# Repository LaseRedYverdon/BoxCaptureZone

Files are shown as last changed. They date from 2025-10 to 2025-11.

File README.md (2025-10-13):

# Box Capture de Zone – LaseRed Yverdon

##  Cahier des charges

- **But du projet** : Coffre électronique avec digicode, boutons lumineux, LEDs RJB, son, et verrouillage par électro-aimant.

- **Contraintes** :
    
    - Matériel robuste (usage intensif).
        
    - Maintenance simple.
        
    - Audio de bonne qualité.
        
    - Mise à jour facile des énigmes et sons gérées à distance. 
        
    - Intégration dans un coffre résistant.

---

****
##  Architecture générale

### Schéma fonctionnel

```mermaid
graph TD
    A[Clavier numérique] -->|Entrée code| B[Arduino UNO]
    B -->|Contrôle| C[Électro-aimant]
    B -->|Affiche énigme| D[Écran digital]
    B -->|État LEDs| E[10 LEDs RJB]
    B -->|Boutons équipe| F[4 Boutons lumineux]
    G[Raspberry Pi] -->|Énigme / Code| B
    G -->|Audio / Musique| H[Haut-parleur + ampli]
```

```

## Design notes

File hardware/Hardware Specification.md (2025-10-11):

# Hardware Specification

**Date :** 11/10/2025  
**Version :** 1.0

---

## Vue d’ensemble

- L’Arduino Nano est **alimenté directement par le Raspberry Pi** via le câble USB (5V).
    
- Le Raspberry Pi et l’Arduino partagent la **masse commune (GND)**.
    
- La **communication** entre Nano et Raspberry se fait par **USB série**. Avec le cable d'alimentation du nano
    
- Le **12 V** est utilisé uniquement pour : électro-aimant, relais et luminaires (géré par le raspberry).
    
- Tous les périphériques externes (digikey, boutons, LCD, électro-aimant, relais) doivent être branchés via des **connecteurs amovibles** (borniers ou connecteurs à levier).

---

## Schéma simplifié

```
                 +---------------------+
                 |     ARDUINO NANO    |
                 |                     |
        5V  <----| Alimentation depuis Raspberry Pi |
       GND  <----| Masse commune avec Raspberry Pi et périphériques |
                 |                                |
        D0  ---->| Libre / réservé debug          |
        D1  ---->| Libre / réservé debug          |
        D2  ---->| DATA0 Wiegand <-----+---- Clavier métallique Wiegand 26
        D3  ---->| DATA1 Wiegand <-----+---- Clavier métallique Wiegand 26
        D4  ---->| Bouton ROUGE  <-----+---- Bouton poussoir LED 16mm
        D5  ---->| Bouton BLEU   <-----+---- Bouton poussoir LED 16mm
        D6  ---->| Bouton JAUNE  <-----+---- Bouton poussoir LED 16mm
        D7  ---->| Bouton VERT   <-----+---- Bouton poussoir LED 16mm
        D8  ---->| Relais ROUGE  ----> Commande relais (électro-aimant)
        D9  ---->| Relais BLEU   ----> Commande relais (lampes ou autre charge)
       D10  ---->| 74HC595 LATCH ----> Latch pin 74HC595 (pour LEDs RJB)
       D11  ---->| 74HC595 DATA ----> Data pin 74HC595 (pour LEDs RJB)
       D12  ---->| Libre / futur usage audio (géré par Raspberry)
       D13  ---->| 74HC595 CLOCK ---> Clock pin 74HC595 (pour LEDs RJB)
        A4  <--> | I2C SDA  <--------> LCD 1602 I2C (connecteur externe)
        A5  <--> | I2C SCL  <--------> LCD 1602 I2C (connecteur externe)
       A0-A3     | Libre (capteurs/futurs)
       A6-A7     | Libre (capteurs/futurs)
                 +---------------------+

   Entrée 12V : embout rond DC → Relais / électro-aimant / lampes
   Connecteurs externes :
     • Clavier Wiegand (4 fils)
     • Boutons LED (3 fils chacun : signal, +5V, GND)
     • LCD I2C (4 fils)
     • Relais pour électro-aimant et lampes
     • Alimentation 12V
```

---

## Branchements détaillés

**Clavier Wiegand 26**

```
   +12V  ---> VCC clavier
   GND   ---> GND commun
   DATA0 ---> D2 Nano
   DATA1 ---> D3 Nano
   Connecteur 4 broches
```

**Boutons poussoirs LED**

```
   D4/D5/D6/D7 ---> entrée signal
   Autre côté bouton ---> GND
   LED intégrée (si présente) ---> +5V via résistance
   Connecteur 3 broches : Signal / +5V / GND
```

**Shift register 74HC595 (10 LEDs RJB)**

```
   D10 ---> LATCH
   D11 ---> DATA
   D13 ---> CLOCK
   QA–QH ---> LEDs (via résistances) ---> GND
   Si plus de 8 LEDs : cascade second 74HC595
```

**Relais (électro-aimant et lampes)**

```
   D8/D9 ---> IN1/IN2 du module relais
   VCC module ---> 5V Nano
   GND module ---> GND commun
   Sortie relais :
     COM ---> entrée 12V (embout DC)
     NO  ---> électro-aimant ou lampe
   Protection : diode roue libre si DC
```

**LCD 1602 I²C**

```
   SDA ---> A4
   SCL ---> A5
   VCC ---> 5V
   GND ---> GND
   Connecteur 4 broches
```

**Communication avec Raspberry Pi**

```
   USB Nano <--> Raspberry Pi
   Alimentation + communication série
   GND commun
```

**Alimentation générale**

```
   5V Nano <--- Raspberry Pi
   12V ---> relais / électro-aimant / lampes
   GND commun
```

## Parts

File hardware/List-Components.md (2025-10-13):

## List of components

### 🔹 1. Unité de contrôle

- **Arduino UNO**

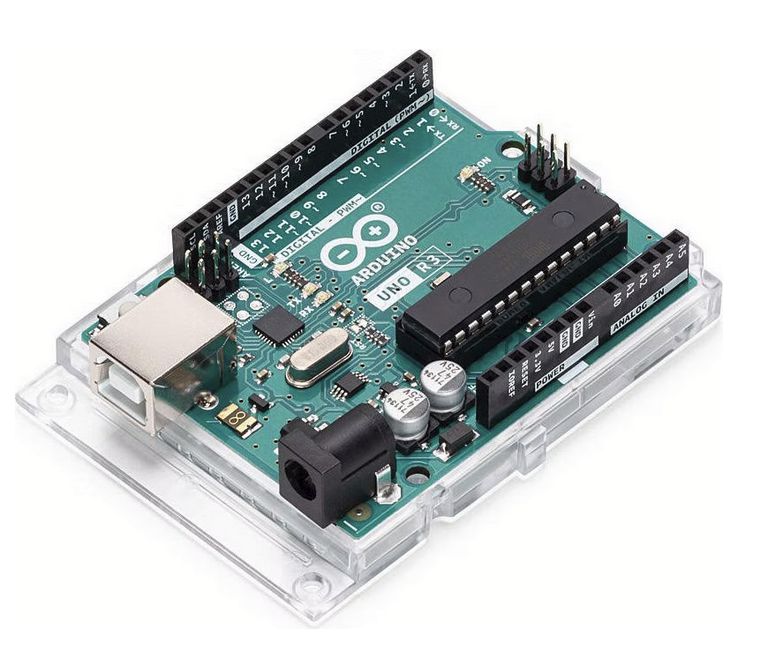
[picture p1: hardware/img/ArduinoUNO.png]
  

  - [Lien fournisseur](https://www.galaxus.ch/fr/s1/product/arduino-uno-rev3-carte-de-developpement-kit-5764177)
  - Dimensions : …
  - Notes : choisi pour son nombre d’entrées/sorties.
        
- **Raspberry Pi (3B+/4)**

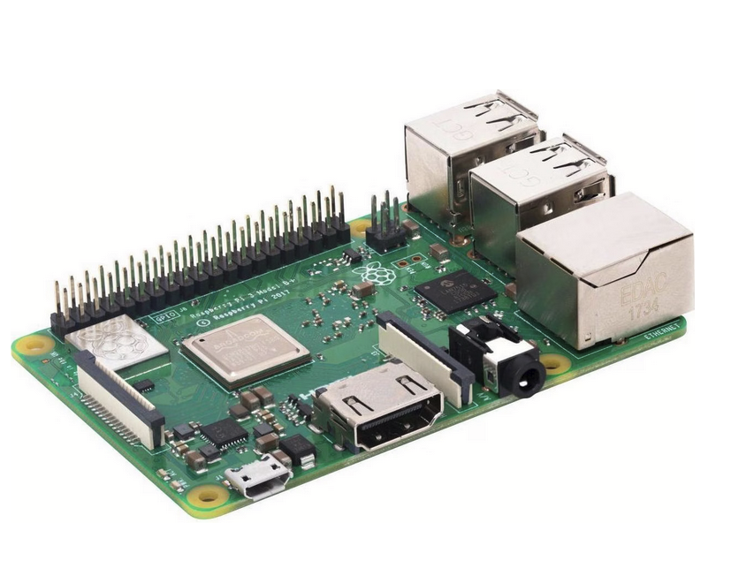
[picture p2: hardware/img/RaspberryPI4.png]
  

  - [Lien fournisseur](https://www.galaxus.ch/fr/s1/product/raspberry-pi-3-model-b-carte-de-developpement-kit-8024081)
  - Dimensions : …
  - Notes : gère l’audio et la lecture des énigmes.

---

### 🔹 2. Interface utilisateur

- **Clavier numérique métallique (digicode)**

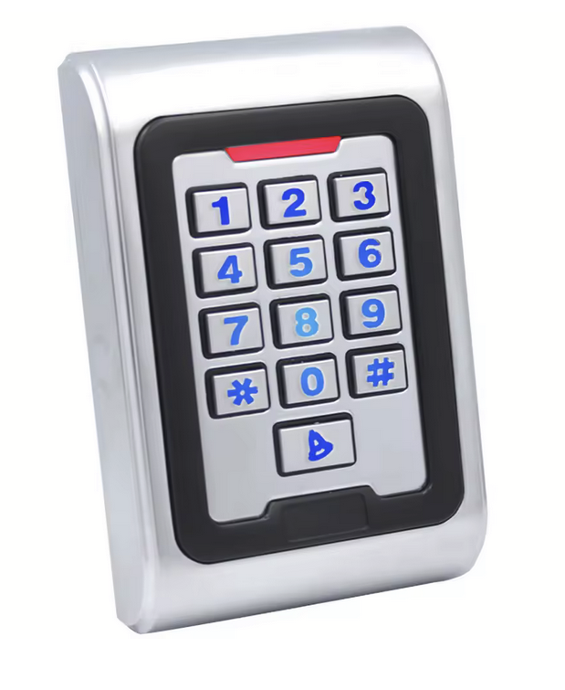
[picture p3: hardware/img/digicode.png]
  

  - [Lien fournisseur](https://de.aliexpress.com/item/1005002655939418.html)
  - Dimensions : …
  - Notes : Le keypad, ou digicode, est une matrice de boutons dont l’état (0 ou 1) peut être détecté par un microcontrôleur. Lorsqu’on appuie sur un bouton, il ferme le circuit reliant la ligne et la colonne correspondantes. Ce type de montage permet de gérer 16 boutons avec seulement 8 entrées.

- **Écran digital (LCD ou OLED)**

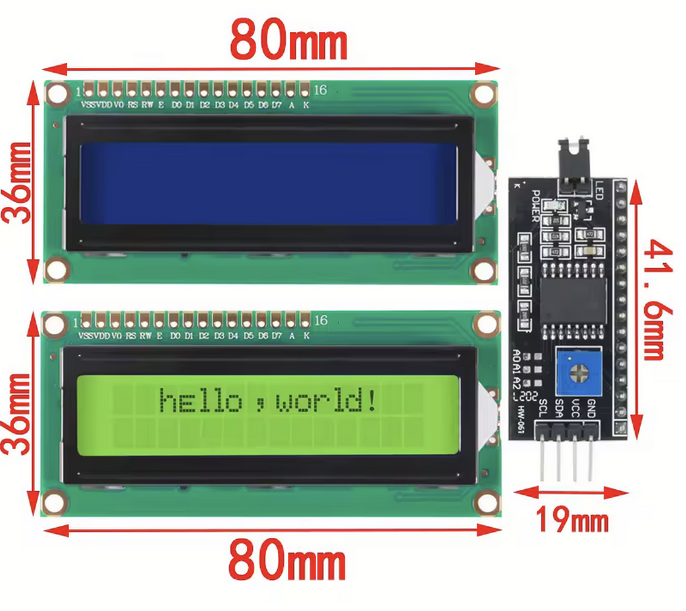
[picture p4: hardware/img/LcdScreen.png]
  

  - [Lien fournisseur](https://de.aliexpress.com/item/1005006086057327.html)
  - Dimensions : …
  - Notes : affichage des énigmes / clues.

- **Boutons lumineux métalliques (R, B, J, V)**

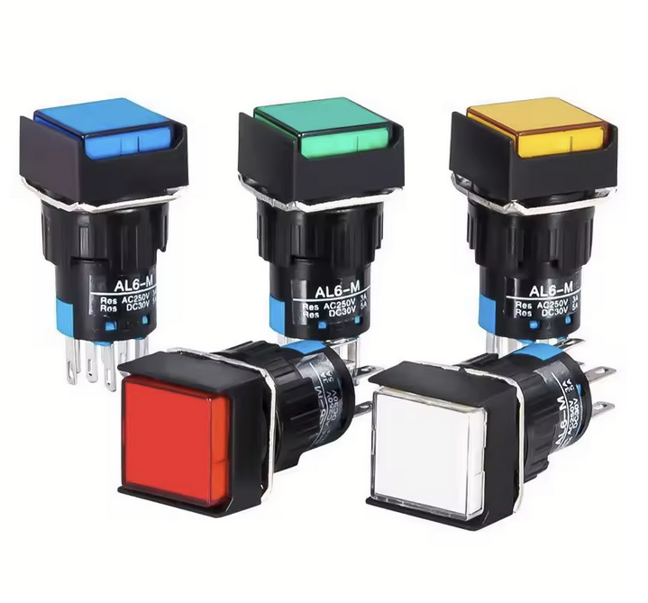
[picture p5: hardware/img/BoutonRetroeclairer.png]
  

  - [Lien fournisseur](https://de.aliexpress.com/item/1005009072059590.html)
  - Dimensions : …
  - Notes : rétroéclairés, usage intensif.

- **LEDs RGB (10 unités)**

  

  - [Lien fournisseur](https://de.aliexpress.com/)
  - Dimensions : …
  - Notes : utilisées pour compte à rebours et affichage.

---

### 🔹 3. Système de verrouillage

- **Électro-aimant 12 V NC (Normally Closed)**

  

  - [Lien fournisseur](https://de.aliexpress.com/)
  - Dimensions : …
  - Notes : coffre verrouillé par défaut, robuste, prévu pour usage intensif.

---

### 🔹 4. Audio

- **Module ampli classe D (ex : PAM8403, 5–10 W)**

  

  - [Lien fournisseur](https://de.aliexpress.com/)
  - Dimensions : …
  - Notes : compact, efficace.

- **Haut-parleur 8 Ω / 5–10 W**

  

  - [Lien fournisseur](https://de.aliexpress.com/)
  - Dimensions : …
  - Notes : bonne qualité sonore, musique + sons.

---

### 🔹 5. Alimentation

- **Alim principale 12 V DC (5 A)**

  

  - [Lien fournisseur](https://de.aliexpress.com/)
  - Notes : alimente électro-aimant et, via convertisseur, le reste.

- **Convertisseur DC-DC (12 V → 5 V 3 A)**

  

  - [Lien fournisseur](https://de.aliexpress.com/)
  - Notes : pour Raspberry Pi et Arduino.

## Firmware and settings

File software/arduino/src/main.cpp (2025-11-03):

/*
  ============================================================================
  Projet : Box Capture de Zone - LASERED Yverdon
  Système : Arduino Nano (unité de contrôle)
  Objet   : Gestion du digicode, LEDs, boutons, et électro-aimant
  Auteur  : Mirco Profico
  ============================================================================

   Schéma de connexion (Arduino Nano)

  ┌─────────────────────────────┬────────────┬────────┬────────────────────────────┐
  │ Élément                    │ Broche     │ Type   │ Description                │
  ├─────────────────────────────┼────────────┼────────┼────────────────────────────┤
  │ Clavier numérique 4x4      │ D2–D5      │ Entrée │ Lignes du digicode         │
  │                            │ D6–D9      │ Entrée │ Colonnes du digicode       │
  │ Écran LCD (I2C)            │ A4 (SDA)   │ Sortie │ Communication I2C          │
  │                            │ A5 (SCL)   │ Sortie │                            │
  │ Électro-aimant (MOSFET)    │ D10        │ Sortie │ Verrouillage du coffre     │
  │ Bouton Rouge               │ D11        │ Entrée │ Équipe rouge               │
  │ Bouton Bleu                │ D12        │ Entrée │ Équipe bleue               │
  │ Bouton Jaune               │ D13        │ Entrée │ Équipe jaune               │
  │ Bouton Vert                │ A0         │ Entrée │ Équipe verte               │
  │ Registre à décalage 74HC595│ D14 (DATA) │ Sortie │ Données LEDs internes      │
  │                            │ D15 (LATCH)│ Sortie │ Verrouillage du registre   │
  │                            │ D16 (CLOCK)│ Sortie │ Horloge de décalage        │
  │ Communication série (Pi)   │ D0 (RX)    │ Série  │ Réception depuis Pi        │
  │                            │ D1 (TX)    │ Série  │ Envoi vers Pi              │
  │                            │ A6         │ Sortie │                            │
  │ Bouton Reset global        │ A7         │ Entrée │ Réinitialisation système   │
  └─────────────────────────────┴────────────┴────────┴────────────────────────────┘

 Notes :
  - Clavier 4x4 géré en balayage matriciel (8 broches)
  - Bus I2C partagé uniquement par l’écran
  - Les LEDs internes peuvent être reliées via registre à décalage (74HC595)
  - Communication série bidirectionnelle avec Raspberry Pi
  - Tous les boutons utilisent résistances pull-down internes ou externes

  ============================================================================
*/

#include <Wiegand.h>
#include <Wire.h>

#include "digicode.ino"       // lecture code à 4 chiffres
#include "lock.ino"           // contrôle électro-aimant
#include "buttons.ino"        // boutons équipe
#include "leds.ino"           // LEDs via 74HC595
#include "comm.ino"           // communication série avec Pi
#include "screen.ino"

const int secretCode = 1060;

void setup() {
    Serial.begin(9600);

    while (!Serial) {}

    commSend("SYSTEM;READY");
    lcdShowMessage("SYSTEM;READY", "");

    initDigicode();      // configure les broches D2/D3 et interne
    initLock();          // configure broche électro-aimant
    initButtons();       // configure les 4 boutons couleur
    initShiftRegister(); // configure registre à décalage pour LEDs
    initComm();          // initialise communication série avec Pi
    initLCD();           // initialise l'écran lcd

    lcdShowMessage("Enigme : 5050 + 10", "");
}

void loop() {
    // 1) Lecture du digicode
    int userCode = readDigicode(); // renvoie le code entré par le joueur

    if (userCode == secretCode) {
        // Déverrouillage automatique non bloquant
        openBox(true); // démarre le déverrouillage et lance le timer pour verrouillage automatique
        lcdShowMessage("Access Granted", "Open box");
        commSend("ACCESS;GRANTED");
    }

    // 2) Gestion non bloquante du coffre
    // lockHandling() gère automatiquement la remise en verrou après délai
    lockHandling(); // à créer ou adapter si openBox()/closeBox() gèrent déjà le timer

    // 3) Lecture et traitement des boutons couleur
    pollButtons(); // gère short press et long press

    // 4) Mise à jour LEDs bargraph selon capture équipe
    // setBargraph(teamCounts); // si implémenté

    // 5) Envoi des infos au Raspberry Pi
    // sendTeamStatus(); // messages type "TEAM;R;3"

    delay(10); // léger délai pour ne pas saturer le Nano
}

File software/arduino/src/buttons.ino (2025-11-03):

// buttons.ino
// Gestion des boutons : 4 boutons d'équipe avec pression courte et longue (pour reset)

#define REQUIRED_PRESS_SECONDS 5 // durée pour considérer un appui long simultané
extern uint8_t teamCounts[4];  // compteur des captures pour chaque équipe
extern uint8_t captureState;   // état de capture de la zone
extern void commSend(const String& msg); // fonction d'envoi série vers le Raspberry
extern void lcdShowMessage(const char *line1, const char *line2); // affichage LCD

// broches des boutons
const uint8_t BTN_PINS[4] = { 4, 5, 6, 7 }; // R, B, J, V
const uint16_t DEBOUNCE_MS = 30;            // anti-rebond logiciel
const uint16_t LONGPRESS_MS = 5000;         // durée pour appui long individuel (ms)

// tableaux d'état pour le debounce et appuis longs
unsigned long lastChange[4] = { 0,0,0,0 };
bool lastState[4] = { HIGH,HIGH,HIGH,HIGH }; // INPUT_PULLUP -> HIGH au repos
unsigned long pressStart[4] = { 0,0,0,0 };

// initialisation des boutons
void initButtons() {
    for (uint8_t i = 0; i < 4; i++) {
        pinMode(BTN_PINS[i], INPUT_PULLUP);
        lastState[i] = digitalRead(BTN_PINS[i]);
        lastChange[i] = millis();
        pressStart[i] = 0;
    }
    Serial.println("Buttons: initialisation terminée");
}

// fonction appelée lors d'une pression courte sur un bouton
void onButtonShortPress(uint8_t teamIdx) {
    Serial.print("BTN;COURT;"); Serial.println(teamIdx);

    // si le coffre est ouvert, on enregistre la capture
    if (captureState == IDLE) {
        captureState = CAPTURE_PENDING;
        // incrémente le compteur de l'équipe (max 10)
        teamCounts[teamIdx] = (teamCounts[teamIdx] < 10) ? (teamCounts[teamIdx] + 1) : 10;
        commSend("CAPTURE;TEAM;" + String(teamIdx));
        lcdShowMessage("Capturé par l'équipe",
            (teamIdx == 0 ? "ROUGE" : teamIdx == 1 ? "BLEU" : teamIdx == 2 ? "JAUNE" : "VERT"));
    } else {
        // si déjà capturé, logique simplifiée : envoie info pression
        commSend("BTN;PRESS;" + String(teamIdx));
    }
}

// fonction appelée lors d'un appui long simultané sur les 4 boutons
void onButtonLongPress() {
    Serial.println("BTN;LONG;TOUS -> RESET ZONE");
    commSend("RESET;ZONE");

    // remise à zéro des compteurs et état capture
    for (uint8_t i = 0; i < 4; i++) teamCounts[i] = 0;
    captureState = IDLE;
    lcdShowMessage("Zone Réinitialisée", "");
}

// lecture et gestion des boutons (appelée à chaque loop)
void pollButtons() {
    unsigned long now = millis();
    bool allPressed = true;

    for (uint8_t i = 0; i < 4; i++) {
        bool st = digitalRead(BTN_PINS[i]); // HIGH repos, LOW pressé

        // changement d'état détecté -> gestion debounce
        if (st != lastState[i]) {
            if ((now - lastChange[i]) > DEBOUNCE_MS) {
                lastChange[i] = now;
                lastState[i] = st;

                if (st == LOW) {
                    // bouton pressé
                    pressStart[i] = now;
                } else {
                    // bouton relâché
                    unsigned long held = (pressStart[i] ? (now - pressStart[i]) : 0);
                    pressStart[i] = 0;

                    if (held >= LONGPRESS_MS) {
                        // appui long individuel ignoré (seulement 4 boutons simultanés déclenchent reset)
                    } else {
                        // appui court
                        onButtonShortPress(i);
                    }
                }
            }
        }

        // vérifie si tous les boutons sont actuellement pressés
        if (digitalRead(BTN_PINS[i]) != LOW) allPressed = false;
    }

    // vérifie si les 4 boutons sont pressés et maintenus > REQUIRED_PRESS_SECONDS
    static unsigned long allPressedStart = 0;
    if (allPressed) {
        if (allPressedStart == 0) allPressedStart = now;
        if ((now - allPressedStart) >= (REQUIRED_PRESS_SECONDS * 1000UL)) {
            // déclenche le reset de zone
            onButtonLongPress();
            allPressedStart = 0;
            // courte pause pour debounce
            delay(200);
        }
    } else {
        allPressedStart = 0;
    }
}

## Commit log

2025-10-17 avancement sur le schéma
    [ArduinoUno_Rpi.SchDoc, BoxCaptureZone_Hardware_V1_0_0.PrjPcb, Schlib1.SchLib]
2025-10-27 il faut réflchir pour la connectique
    [ArduinoUno_Rpi.SchDoc]
2025-11-03 Add main code and button, comm, digicode, lock and screen code
2025-11-03 schéma bientot fini
    [ArduinoUno_Rpi.SchDoc, Schlib1.SchLib]
2025-11-03 Update logical game and main.ino. Button is not finish
2025-11-12 schéma fini, manque de mise au propre
    [ArduinoUno_Rpi.SchDoc, Schlib1.SchLib]
2025-11-13 schéma fini
    [ArduinoUno_Rpi.SchDoc]
